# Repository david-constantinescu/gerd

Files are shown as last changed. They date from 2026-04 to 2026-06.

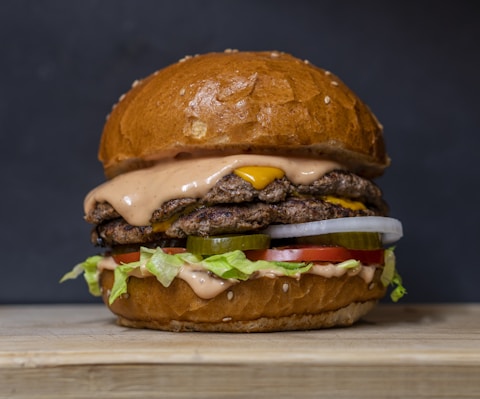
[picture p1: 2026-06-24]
simulator/scripts/food_fixtures/burger.jpg

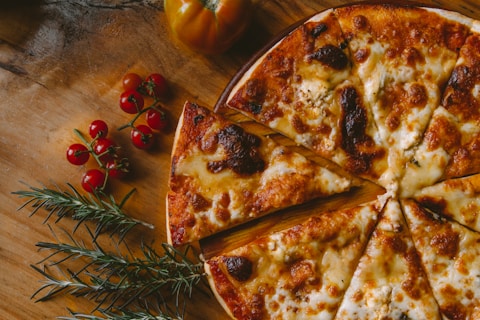
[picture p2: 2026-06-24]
simulator/scripts/food_fixtures/pizza.jpg

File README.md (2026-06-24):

# UpRight

An offline, waist-worn wearable for people with GERD / acid reflux. Runs on a
Raspberry Pi Zero 2 W.

> Reference docs live in `reference docs/`. Start with
> [`oled-mockups.md`](reference%20docs/oled-mockups.md) for on-device UI layout and
> **two-button** controls (GPIO 20 / 21 — no rotary encoder).

## What it does

- **Posture tracking** with an MPU6050 IMU; vibration + voice alerts when you
  slouch, with a 2 minute lying-down grace period and configurable cooldowns.
- **Food risk analysis** — point the OV9712 camera at your meal; a bundled,
  on-device TFLite model (Google's AIY Food V1, 2024 food classes) **names the
  dish**, then maps it to a GERD risk tier + how long to stay upright using a
  ~380-entry food dictionary plus a keyword fallback. Result + spoken advice on
  the OLED.
- **Sleep position** tracking with up to 3 vibration nudges per night when
  you roll onto your right side / back / front.
- **Posture** via MPU6050 IMU on the waist clip.
- **Medication reminders** with button-press acknowledgment.
- **Local Flask PWA** dashboard reachable at `http://<hostname>.local` (mDNS)
  on your own Wi-Fi. First-time setup needs no app: with no network configured the
  device raises a temporary **UpRight-Setup** Wi-Fi AP — scan the on-screen Wi-Fi
  QR to join it, and a **captive portal** opens the Wi-Fi picker on your phone by
  itself (no URL to type). Add/switch networks later from Settings → Network.
- **Self-maintaining clock** — the RTC-less Pi keeps correct time via chrony +
  fake-hwclock, with an HTTP-time fallback for networks that block NTP.

No cloud, no app store.

The full subsystem layout and milestone breakdown lives in
[`reference docs/BUILD.md`](reference%20docs/BUILD.md). Wiring pinout in
[`reference docs/WIRING.md`](reference%20docs/WIRING.md). Mac → GitHub → Pi dev
workflow in [`reference docs/DEV.md`](reference%20docs/DEV.md). **For a complete
project brief / agent handoff (current state + the open Wi-Fi-AP issue), read
[`reference docs/HANDOFF.md`](reference%20docs/HANDOFF.md).**

## Quick start (on a fresh Pi Zero 2 W)

```bash
curl -fsSL https://raw.githubusercontent.com/david-constantinescu/gerd/main/install.sh | bash
```

This clones the repo, installs every system + Python dependency (including the
`ai-edge-litert` runtime for the food model), enables I²C and I²S, enables mDNS
(avahi) + NetworkManager, configures the setup-AP captive portal and time sync,
and installs both systemd units (`upright.service` for the firmware loop,
`upright-web.service` for the Flask PWA). Pre-seed the first Wi-Fi network with
Raspberry Pi Imager, or use the on-device **UpRight-Setup** AP on first boot;
after that, manage networks from the dashboard's Settings → Network page.

> The bundled food model is a ~20 MB binary committed to the repo. The Pi runs
> **Debian 13 (trixie)** on Python 3.13, where the runtime must be
> `ai-edge-litert` (`tflite-runtime` has no 3.13 wheel) — `install.sh` handles
> this. To flash an SD card directly from macOS instead of booting the Pi, see
> the `e2fsprogs`/`e2tools` workflow in
> [`reference docs/HANDOFF.md`](reference%20docs/HANDOFF.md) §8.

## Quick start (development on macOS)

```bash
git clone https://github.com/david-constantinescu/gerd.git
cd gerd/firmware
python3 -m venv .venv && source .venv/bin/activate
pip install -e ".[dev]"
pytest -q
python -m upright.main --dry-run
```

The HAL imports its Pi-only libraries lazily (`RPi.GPIO`, `smbus2`,
`luma.oled`) so the package imports cleanly on macOS for unit tests, even though
the actual hardware drivers can't run there. The food model runs on macOS too if
you `pip install ai-edge-litert` (the same runtime used on the Pi). The
[simulator](simulator/README.md) runs the whole firmware against a virtual HAL.

## Repo layout

```
firmware/         Python package that runs on the Pi
  src/upright/   Source: HAL, FSM, services, web app
  models/         Bundled food classifier (.tflite + .labels.txt)
  scripts/        Per-sensor bring-up helpers
  systemd/        Service files (firmware loop + Flask PWA)
  tests/          pytest, runs on Mac (104 tests)
  data/foods.json Food risk dictionary (~380 entries)
simulator/        Virtual Pi bench: real firmware + sim HAL + HTTP API
scripts/          Pi install + ops helpers (incl. upright-set-time)
reference docs/   HANDOFF, BUILD, DEV, WIRING, PI_REMOTE_RUNBOOK, mockups, spec
cad/              Enclosure CAD (placeholder)
install.sh        One-shot Pi installer (idempotent)
```

## License

MIT.

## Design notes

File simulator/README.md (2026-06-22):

# UpRight — Raspberry Pi Simulator

A **virtual Raspberry Pi bench** that runs the *real* firmware from
[`../firmware`](../firmware) with a simulated hardware layer, surfaced through a
browser UI and an HTTP control API.

You click buttons, drag posture/battery sliders, and stream your webcam — and
the actual `upright` firmware (boot sequence, finite-state machine, menu system,
posture detection, alert/haptics, the *exact* `ui.render` frames it pushes to
the OLED/TFT) reacts as if it were on the device. The screen you see is the
genuine 160×128 ST7735R panel output, rendered by the firmware itself.

> **Why not QEMU?** A full-system emulator boots the ARM CPU and Linux, but it
> does **not** emulate the GPIO buttons, I²C IMU, SPI TFT, or USB camera — the
> peripherals that *are* this firmware. Under QEMU the code falls back to the
> same empty stubs it uses on a Mac. This simulator instead runs the real
> Python firmware natively (Python behaves identically to the Pi) and provides
> interactive, faithful simulation of the peripherals — which is *more* accurate
> for this project, not less.

## What is real vs. simulated

| Layer | In the simulator |
|---|---|
| Boot sequence, FSM, menus, services, posture/sleep/meds logic | **Real firmware code, unmodified** |
| `ui.render` → display frames (160×128 RGB) | **Real** — captured and streamed to the browser |
| Web-app inbox commands (meal, symptom, calibrate, …) | **Real** — same SQLite inbox path as the PWA |
| Buttons A/B, encoder | Simulated → real `BUTTON_PRESS` / `ENCODER_*` events |
| IMU (pitch/roll) | Simulated from sliders → real `POSTURE_SAMPLE` events (incl. EMA smoothing) |
| Battery, heart-rate | Simulated → real `POWER_SAMPLE` / `HRV_SAMPLE` events |
| Camera (USB UVC) | Your **webcam** (or an uploaded image) → real `camera.capture()` |
| Motor (haptics), audio | Captured and shown as indicators in the UI |

The firmware's HAL has a clean seam (lazy hardware imports + `--dry-run`), so the
simulator swaps only the lowest layer via monkeypatching — **the firmware source
is never touched.** See [`sim/hal_sim.py`](sim/hal_sim.py).

## Run it

```bash
cd simulator
# use the firmware venv (already has flask + pillow + numpy):
../firmware/.venv/bin/python run.py
# → open http://localhost:8000
```

Flags:

| Flag | Effect |
|---|---|
| `--port 9000` | listen on a different port (default 8000) |
| `--fresh` | reset the `.simdata` sandbox before starting |
| `--demo` | enable `demo_mode` (synthetic week data; disables live posture control) |
| `--open` | open the bench in your default browser |

Firmware data is sandboxed in `simulator/.simdata/` (seeded once from
`firmware/data/`), so running the simulator **never clobbers the real device DB.**

## HTTP / JSON control API (AI-controllable)

Any agent can drive the device with plain HTTP. The screen is readable as a PNG
(for vision models) and the full state as JSON.

| Method & path | Body | Purpose |
|---|---|---|
| `GET /api/state` | — | FSM state, menu, sensors, motor/audio, log tail |
| `GET /screen.png?scale=N` | — | current panel frame as PNG (native 160×128 × N) |
| `GET /stream.mjpeg` | — | live MJPEG screen stream |
| `POST /api/button` | `{"button":"a\|b","pattern":"single\|double\|triple"}` | press a button |
| `POST /api/encoder` | `{"action":"cw\|ccw\|click"}` | rotate/click encoder |
| `POST /api/posture` | `{"pitch":<deg>,"roll":<deg>}` | set IMU posture |
| `POST /api/battery` | `{"pct":0-100,"low":bool}` | set battery |
| `POST /api/hrv` | `{"bpm":<n>,"rmssd":<ms>}` | inject a heart-rate sample |
| `POST /api/camera/frame` | raw `image/*` bytes, or `{"image":"<dataURL\|base64>"}` | feed a camera frame |
| `POST /api/command` | `{"command":"<name>","payload":{…}}` | queue a web-app inbox command |

`/api/command` names mirror the real PWA: `meal`, `symptom`, `water`,
`calibrate`, `open_menu`, `sleep`, `haptic`, `idle`, `demo_enter`, `demo_exit`,
`med_ack`, `config_reload` (raw inbox kinds like `cmd_open_menu` also accepted).

### Example: an agent drives the device

```bash
B=http://localhost:8000
curl -s $B/api/command -d '{"command":"open_menu"}' -H 'Content-Type: application/json'
curl -s $B/api/button  -d '{"button":"a"}'          -H 'Content-Type: application/json'   # navigate
curl -s $B/api/button  -d '{"button":"b"}'          -H 'Content-Type: application/json'   # select
curl -s $B/api/posture -d '{"pitch":35,"roll":2}'   -H 'Content-Type: application/json'   # slouch
curl -s $B/screen.png?scale=4 -o screen.png                                                # read the screen
curl -s $B/api/state | python -m json.tool                                                 # read the state
```

## Layout

```
simulator/
├── run.py            # entrypoint: boots firmware + serves the bench
├── sim/
│   ├── runner.py     # path/data sandbox, imports firmware, runs main() in a thread
│   ├── hal_sim.py    # simulated HAL backends + monkeypatch installer (no firmware edits)
│   ├── server.py     # Flask: bench UI + control API + screen stream
│   └── state.py      # SimDevice: thread-safe bridge (inputs ⇄ outputs ⇄ frames)
└── web/              # the browser bench (index.html, bench.css, bench.js)
```

## Notes & limits

- The encoder is *not fitted* on the real hardware (shares GPIO with the motor),
  so the firmware mostly ignores encoder events — the controls are provided for
  completeness.
- Food-photo classification runs for real in the sim: the bundled AIY Food model
  ships in `firmware/models/`, and `pip install ai-edge-litert` (in
  `requirements.txt`) provides the runtime on macOS. Enable the webcam or upload a
  food image, capture, and you get a real dish name + GERD risk. Without the
  runtime it degrades to "Not recognized".
- Posture alerts/haptics fire under the firmware's real timing/threshold rules
  (sustained slouch, post-meal strictness, etc.) — set a slouch and wait.

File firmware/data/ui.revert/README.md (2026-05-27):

# UI revert snapshot

Saved **before** battery icon + two-button navigation update (A tap=up, A hold=back, B tap=down, B hold=select).

Restore on Mac or Pi:

```bash
bash firmware/scripts/ui_revert.sh
sudo systemctl restart upright   # on Pi
```

Files: `ui.py`, `ui_theme.py`, `button.py`, `manager.py`, `menu.py`

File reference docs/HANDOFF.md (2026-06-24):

# UpRight — Engineering Handoff & Agent Brief

> **Purpose of this file.** A single, self-contained brief so another engineer
> or AI agent can pick up this project cold. It carries the full context: what
> the device is, how the code is laid out, what has been built recently, the
> exact dev/build/flash/SSH environment, and the **open problem** (Wi-Fi setup
> AP on real hardware). Read this top to bottom before touching anything.
>
> Last updated: 2026-06-21. Repo HEAD at handoff: `5feb4fa` on `main`.

---

## 1. What the product is

**UpRight** is an **offline, waist-worn wearable for people with GERD / acid
reflux**, built on a **Raspberry Pi Zero 2 W**. Everything runs on-device — no
cloud, no app store, no companion app required.

Features:
- **Posture tracking** (MPU6050 IMU) → vibration + spoken alerts on slouch, with
  a lying-down grace period and cooldowns.
- **Food risk analysis** — point the OV9712 USB camera at a meal, an on-device
  TFLite model names the dish, and it's mapped to a GERD risk tier + how long to
  stay upright. (See §4 — this was just made to actually work.)
- **Sleep position** tracking with vibration nudges when you roll onto your
  right/back/front.
- **Posture** via MPU6050 IMU (no heart-rate sensor on this hardware revision).
- **Medication reminders** with button-press acknowledgment.
- **Local Flask PWA** dashboard at `http://<hostname>.local`, plus first-time
  Wi-Fi onboarding via an on-screen QR (see §5).

Two physical buttons (GPIO 20 / 21), a 160×128 ST7735R SPI TFT, a vibration
motor, and an I²S speaker. No rotary encoder despite some legacy naming.

---

## 2. People, accounts, machines

| Thing | Value |
|---|---|
| GitHub repo | `https://github.com/david-constantinescu/gerd` (branch `main`) |
| `gh` CLI auth | authenticated as `david-constantinescu` |
| Owner email | david.constantinescu1982@gmail.com |
| Local checkout (macOS) | `~/Downloads/upright/gerd` |
| Pi hostname | `softhoarders-pi` (mDNS `softhoarders-pi.local`) |
| Pi user | `softhoarders` |
| Pi project path | `~/upright` (i.e. `/home/softhoarders/upright`) |
| Web dashboard login | `softhoarders` / `0031` |
| Pi OS | **Debian 13 (trixie)**, NetworkManager-managed |
| Pi Python | **3.13**, venv at `~/upright/.venv` created `--system-site-packages` |

> Note the Pi runs plain **Debian 13 trixie**, not "Raspberry Pi OS Bookworm".
> This matters for package/runtime availability (see §4 runtime note).

---

## 3. Repo layout & architecture

```
firmware/                  Python package that runs on the Pi
  src/upright/
    main.py                entrypoint; starts HAL threads + ModeManager loop
    config.py              Tunables dataclass + all file paths (DATA_DIR, MODELS_DIR…)
    events.py              EventBus (queue.Queue) + EventType enum
    hal/                   hardware abstraction (lazy Pi-only imports)
      display.py camera.py button.py imu.py motor.py audio.py power.py …
    modes/
      manager.py           ModeManager — the FSM + view-context builder + render loop
      menu.py              two-button menu navigation state
      ui.py / ui_theme.py  OLED renderers (PIL → 160×128)
      states.py            State enum
    services/
      foods.py             food dictionary + TFLite inference (see §4)
      logger.py            SQLite store (self-healing on corruption)
      wifi.py              NetworkManager (nmcli) wrapper + setup-AP funcs
      provisioning.py      raises/drops the setup AP; is_setup_mode()
      netinfo.py           hostname/IP/QR helpers (segno)
      timesync.py          keep the clock correct (chrony nudge + HTTP-Date)
      alerts.py meds.py sleep.py analytics.py demo_seed.py boot.py
    web/
      app.py               Flask PWA + JSON API + captive-portal hook
      templates/           dashboard.html, settings.html, setup.html, …
      static/              app.js, style.css, sw.js
  models/                  food_mobilenetv2_quant.tflite (+ .labels.txt)
  data/                    foods.json, config.json, display.default.json
  systemd/                 upright.service, upright-web.service (@USER@/@DIR@ templated)
  tests/                   pytest (runs on Mac), 104 tests
simulator/                 virtual Pi bench (runs real firmware w/ sim HAL) — see simulator/README.md
scripts/                   pi-install-*.sh, deploy-to-pi.sh, upright-set-time
reference docs/            this file + BUILD/DEV/WIRING/PI_REMOTE_RUNBOOK/…
install.sh                 one-shot Pi installer (idempotent)
```

**Key architecture facts (not obvious from a quick read):**
- The HAL imports Pi-only libs **lazily**, and `main.py` supports `--dry-run`, so
  the package imports and the test suite run on macOS with no hardware.
- Firmware ↔ web talk **only** through the SQLite `inbox` table (polling IPC);
  there is no direct call path between the two processes.
- Rendering is gated: `ModeManager` only repaints the OLED when a "view
  signature" changes, to avoid SPI thrash.
- Two systemd units: `upright.service` (firmware loop, `User=softhoarders`) and
  `upright-web.service` (gunicorn on :80, has `CAP_NET_BIND_SERVICE`). **Both run
  as the non-root user** — so anything needing root (setting the clock) goes
  through a sudoers-allowed helper, not directly.

---

## 4. Food classification — DONE (bundled a real model)

**Problem it fixes:** the food flow never recognized anything because no model
shipped (only a labels file), so `classify()` always returned `None` and the
result screen dead-ended on "unknown / 0%".

**What was done (commit `13bee30`):**
- Bundled **Google's AIY Food V1** quantized TFLite model (2024 food classes,
  ~20 MB, input 192×192 uint8, output uint8 softmax). It lives at
  `firmware/models/food_mobilenetv2_quant.tflite` and is **un-gitignored** (an
  exception in `.gitignore`) so it ships in git and to the SD.
- `foods.py`:
  - `_load_interpreter_cls()` tries `ai_edge_litert` → `tflite_runtime` →
    `tensorflow.lite` (whichever is present).
  - `resolve_label()` keeps the **detected dish name** and maps it to a GERD risk
    tier via `foods.json` (exact/alias, then longest whole-word match), then a
    **keyword fallback** (`_HIGH_RISK_KW`/`_LOW_RISK_KW`: fried/citrus/tomato/
    coffee/chocolate… → HIGH; veg/grains/lean protein → LOW) so any recognized
    food yields useful advice. The model's `__background__` class → `None`.
  - `food_min_confidence` lowered `0.60 → 0.20` (a 2024-class top-1 for real food
    is ~0.3–0.85; non-food sits < 0.15). Set in `config.py` and `data/config.json`.
- `ui.py` ASCII-folds OLED text — the built-in PIL bitmap font renders an em
  dash and accented names (e.g. "Rösti") as a blank "tofu" box.
- Verified end-to-end in the simulator: real photos classify correctly
  (croquettes→"Croquette", pizza→"Neapolitan pizza"/HIGH/score 95), non-food →
  "Not recognized".

**Runtime gotcha (important):** `tflite-runtime` has **no cp313 wheel**, and the
Pi venv is Python 3.13 → the only working runtime there is **`ai-edge-litert`**.
Its `Interpreter` only needs `numpy` at runtime (the protobuf/tqdm deps are for
conversion tools), so it can be vendored as a single wheel. It's listed in the
`[pi]` extra and `simulator/requirements.txt`. On macOS (the sim) `ai-edge-litert`
installs cleanly and runs the model.

---

## 5. Networking & first-time Wi-Fi

> **ROOT CAUSE FOUND & FIXED (2026-06-24, commit `5907a23`).** The device
> "wouldn't connect to anything and the setup AP wouldn't broadcast" because
> Raspberry Pi Imager configured Wi-Fi the **old ifupdown way** in
> `/etc/network/interfaces` *and* NetworkManager was left `[ifupdown]
> managed=false` — so **NM never managed `wlan0`**, and the entire nmcli-based
> firmware Wi-Fi stack silently couldn't touch the radio. Fix: `install.sh` (and
> a direct SD edit) strip the `wlan0` stanza from `/etc/network/interfaces`,
> migrate the ifupdown Wi-Fi into an NM keyfile, and drop
> `/etc/NetworkManager/conf.d/10-upright-manage-wifi.conf` (`managed=true`). Also
> removed a `wifi.py` autoconnect-suppression trap (it persisted
> `autoconnect=no` on saved networks → stranded the device offline forever), and
> added a **boot diagnostic** (`scripts/upright-netdiag.sh` +
> `upright-netdiag.service`) that writes `nmcli`/`iw`/`rfkill`/`dmesg` state to
> `<boot>/upright-netdiag.txt` each boot — readable straight off the SD's FAT
> partition, no SSH. **Still needs confirming on hardware:** boot the patched SD,
> then read `bootfs/upright-netdiag.txt` to see the live radio state.

Background on the design and the (now-fixed) symptoms follows.

### Design
- The old always-on Wi-Fi hotspot was removed in favor of **mDNS** (avahi,
  `softhoarders-pi.local`) + **NetworkManager** Wi-Fi management.
- **First-time provisioning:** when the device has no Wi-Fi, `provisioning.py`
  raises a temporary AP **`UpRight-Setup` / `uprightsetup`** at gateway
  `10.42.0.1` (NM `shared` mode). The OLED Network screen shows a standard
  `WIFI:` join QR. Once the device associates as a client, the AP drops.
- **Captive portal (commit `b0d2316`):** `install.sh` writes
  `/etc/NetworkManager/dnsmasq-shared.d/upright-captive.conf` with
  `address=/#/10.42.0.1`, so while the AP is up every DNS query resolves to the
  gateway. `web/app.py` has a `before_request` hook that, during
  `provisioning.is_setup_mode()`, redirects OS captive-portal probes
  (Android/iOS/Windows/Firefox) and foreign hosts to a clean, **login-free**
  `templates/setup.html` Wi-Fi picker — so the phone auto-opens the setup page
  after joining. On connect it shows the dashboard URL + QR.
- The QR codes were verified decodable with a real reader (OpenCV
  `QRCodeDetector`), including at the 99×99 size rendered on the 128 px panel.

### AP-hardening already applied (commit `5feb4fa`, NOT yet verified on hardware)
`wifi.start_ap()` was hardened because the AP would not broadcast on a real boot:
- It **frees the single radio first** (`nmcli device disconnect wlan0`) — a saved
  network NM keeps auto-retrying otherwise hogs `wlan0` and blocks AP activation.
- It **recreates the profile each time** with explicit WPA2/RSN ciphers
  (`proto rsn`, `pairwise/group ccmp`) and a **fixed 2.4 GHz channel 6** — the
  bare `key-mgmt wpa-psk` form can leave `wpa_supplicant` unable to beacon on some
  `brcmfmac` builds.
- Boot grace cut `30s → 12s` so the AP appears quickly when the saved network is
  unreachable.
- The OLED **online** Network screen now also prints the **LAN IP** under the QR,
  so the device is reachable even when `<host>.local` won't resolve.

### ⚠️ OPEN PROBLEM (where the next agent starts)
On the real Pi the user reports: **"I can scan the QR but it won't connect, and
the `UpRight-Setup` network isn't broadcasting."** Diagnosis so far (all from
inspecting the SD card, since there are **no persistent logs** — the journal is
volatile and gone on reboot):
- Regulatory is fine: `cfg80211.ieee80211_regdom=RO` is set in
  `bootfs/cmdline.txt` (Pi Imager seeded it) and `/lib/firmware/regulatory.db`
  exists. So "no country" is **not** the cause.
- `rfkill` wlan state on disk = `0` (not blocked).
- NetworkManager + `nmcli` installed and enabled; `wpa_supplicant.service` enabled.
- There is a **pre-seeded client profile** `DIGI-Y7wu` (the owner's home ISP),
  `autoconnect` default true. So on boot NM tries to join it.
- The hardened `start_ap()` (free-radio + RSN + ch6) is the current best guess but
  **has not been confirmed on hardware yet.**

To make the Pi reachable for live debugging, a **`SoftHoarders Wi-Fi`** client
profile (psk `SoftHoarders`, `autoconnect-priority=10`) was written directly to
the SD at `/etc/NetworkManager/system-connections/` (mode 0600, root-owned). The
owner's Mac SSH key is **already in** `~softhoarders/.ssh/authorized_keys`, and
`ssh.service` is enabled — so SSH should work **once the Pi and the controlling
machine are on the same network.**

**Current blocker:** the controlling Mac is on **wired ethernet** (`192.168.0.x`);
the Pi joined **`SoftHoarders Wi-Fi`** (a different subnet), so they can't see
each other. A full `192.168.0.0/24` port-22 scan + key-auth probe did **not** find
the Pi (only an unrelated Ubuntu box `softhoardersmuzeu` shares the key).

**Open questions to resolve next:**
1. Is `SoftHoarders Wi-Fi` **2.4 GHz**? The Pi Zero 2 W is 2.4 GHz-only; a
   5 GHz-only hotspot would explain "can't join" entirely.
2. Put the controlling machine on the **same network** as the Pi (or read the
   device's **Settings → Network** screen for the IP it shows) to get SSH access.
3. With SSH access, debug the AP **live** — the right tools are:
   `nmcli -f WIFI-PROPERTIES device show wlan0` (does the driver advertise AP?),
   `sudo nmcli connection up upright-setup` (read the actual failure),
   `iw dev`, `iw reg get`, `dmesg | grep -i brcmfmac`, `journalctl -u NetworkManager -b`.
4. Consider enabling **persistent journald** on the Pi
   (`mkdir -p /var/log/journal && systemctl restart systemd-journald`) so the
   next failure leaves logs.

---

## 6. Clock / time sync — DONE (commits `b0d2316`, `cf9c8ba`)

The Pi Zero 2 W has **no RTC**, so its clock lagged.
- `install.sh` installs/enables **chrony** (`makestep 1 -1`) + **fake-hwclock**
  and sets NTP on — clock is disciplined continuously and survives reboots.
- `services/timesync.py` (started from `main.py`): forces a chrony step on
  boot/network-up and, on networks that block NTP (UDP 123), sets the clock from
  an **HTTPS `Date` header** via the narrow sudo helper
  `scripts/upright-set-time` (allowed in `/etc/sudoers.d/upright-timesync`). It
  runs even when chrony isn't installed, as long as the helper is present — so a
  hand-flashed board still self-corrects.

---

## 7. Dev / build / test (macOS)

```bash
cd ~/Downloads/upright/gerd/firmware
python3 -m venv .venv && source .venv/bin/activate   # already exists in the checkout
pip install -e ".[dev]"          # + `ai-edge-litert` to run the food model locally
.venv/bin/python -m pytest -q    # 104 tests, must stay green
.venv/bin/ruff check src tests   # CI runs this too — must be clean
python -m upright.main --dry-run # run the firmware off-Pi
```

**Simulator** (runs the *real* firmware with a simulated HAL + browser bench +
HTTP control API — the best way to verify UI/flows without hardware):
```bash
cd ~/Downloads/upright/gerd/simulator
../firmware/.venv/bin/python run.py --port 8000   # open http://127.0.0.1:8000
```
Drive it over HTTP: `POST /api/button {button,pattern}`, `/api/posture`,
`/api/camera/frame` (raw JPEG), `/api/command {command}`; read `/api/state`,
`/screen.png`. See `simulator/README.md`.

CI = `ruff check firmware/src firmware/tests` + `pytest`. Keep both green.

---

## 8. Deploying to the Pi

There are **two** deploy paths. Prefer the first.

### A. On the Pi (recommended — applies system config too)
```bash
cd ~/upright && git pull && sudo bash install.sh && sudo reboot
```
This pulls code + the bundled model, installs the `ai-edge-litert` runtime, and
applies the system-level pieces (captive-portal dnsmasq config, chrony,
sudoers + time helper). The food model and the timesync HTTP fallback work from
code alone, but **the captive portal and chrony only fully activate after
`install.sh` runs on the Pi.**

### B. Flash the SD card from macOS (offline, no Pi boot needed)
The Pi rootfs is **ext4**, which macOS can't mount — use `e2fsprogs`/`e2tools`.

```bash
# tools (installed via Homebrew):
export PATH="/usr/local/opt/e2fsprogs/sbin:/usr/local/opt/e2fsprogs/bin:$PATH"
#   e2fsck, debugfs live there; e2cp / e2mkdir / e2ls live in /usr/local/bin

SD=/dev/disk8s2          # ext4 rootfs (the Linux partition; check `diskutil list`)
                         # bootfs (FAT) auto-mounts at /Volumes/bootfs — edit directly

# sudo on this Mac needs Touch ID, which only surfaces when the Bash sandbox is
# OFF. In Claude Code: run Bash with dangerouslyDisableSandbox: true.

sudo e2fsck -fy "$SD"                                   # ALWAYS before & after writing
# read:  sudo debugfs -R "cat /path" "$SD"   (batch many: debugfs -f cmds.txt "$SD")
# write: sudo e2cp -O 1000 -G 1000 -P 0644 local "$SD:/home/softhoarders/upright/…"
#        (use -O 0 -G 0 for root-owned files under /etc, /usr/local/sbin)
# mkdir: sudo e2mkdir "$SD:/path/to/dir"
sudo e2fsck -fn "$SD"; sync; diskutil eject disk8       # finish clean, then eject
```

Things already vendored onto the SD this way (since the Pi was offline / to avoid
re-running install): the food **model**, the **`ai_edge_litert`** runtime
(cp313/aarch64 wheel extracted into `…/.venv/lib/python3.13/site-packages/`),
**`segno`**, the captive-portal/chrony/sudoers config, the `upright-set-time`
helper, and the `SoftHoarders Wi-Fi` NM profile. Verify writes by md5-comparing
files read back with `e2cp` against the repo.

> Editable install: the Pi venv uses a lax `.pth` pointing at
> `~/upright/firmware/src`, so **new Python modules are importable without a
> reinstall** — copying a `.py` file in is enough.

---

## 9. Connecting to the Pi (SSH + finding it on the LAN)

```bash
ssh softhoarders@softhoarders-pi.local         # if mDNS resolves
# the Mac's key is already in the Pi's authorized_keys
```
If mDNS doesn't resolve (common on some networks), find it by IP. **Both machines
must be on the same network/subnet.**
```bash
# scan the local /24 for SSH, then key-auth probe to find the Pi by hostname:
for i in $(seq 1 254); do (nc -G1 -z -w1 192.168.0.$i 22 2>/dev/null && echo .$i) & done; wait
for ip in <candidates>; do
  ssh -o BatchMode=yes -o StrictHostKeyChecking=accept-new -o ConnectTimeout=4 \
      softhoarders@192.168.0.$ip 'hostname' 2>/dev/null
done   # the Pi answers "softhoarders-pi"
```
See `PI_REMOTE_RUNBOOK.md` for service/ops commands once connected.

---

## 10. Status summary & prioritized next steps

**Done & on `main`:** real food classifier + runtime, mDNS, captive-portal Wi-Fi
setup page, clock sync, AP hardening. 104 tests pass, ruff clean. Model + runtime
+ config flashed to the SD; `SoftHoarders Wi-Fi` + SSH key in place.

**Not yet verified on hardware:** the `UpRight-Setup` AP actually broadcasting,
and the food model running on-device (both need a booted, reachable Pi).

**Do next, in order:**
1. **Get SSH on the Pi.** Put the controlling machine on the **same network** the
   Pi joined (`SoftHoarders Wi-Fi`), or use the IP shown on the device's
   Settings → Network screen. Confirm 2.4 GHz (the Pi is 2.4 GHz-only).
2. **Verify the food flow on-device:** trigger a food photo, confirm
   `ai_edge_litert` loads and a dish is recognized. (`journalctl -u upright -f`.)
3. **Fix the setup AP live** using the §5 commands; confirm `UpRight-Setup`
   beacons and a phone can join + auto-open the portal. Update `wifi.start_ap()`
   based on the real `nmcli`/`dmesg` error and add a regression test.
4. **Enable persistent journald** so future failures are debuggable.
5. Push every change to `main`; keep `pytest` + `ruff` green.

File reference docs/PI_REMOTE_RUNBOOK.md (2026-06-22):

# Pi Remote Runbook (SSH + Ops)

This is the practical reference for connecting to the project Pi and managing
the running UpRight app remotely.

## Target machine

- Hostname: `softhoarders-pi.local`
- User: `softhoarders`
- Project path on Pi: `~/upright`
- Firmware path: `~/upright/firmware`

## 1) SSH access

### First-time key setup (Mac)

```bash
# generate key if needed
test -f ~/.ssh/id_ed25519 || ssh-keygen -t ed25519 -C "upright-dev"

# copy key to Pi
ssh-copy-id softhoarders@softhoarders-pi.local
```

### Connect

```bash
ssh softhoarders@softhoarders-pi.local
```

### Quick connectivity check

```bash
ssh -o ConnectTimeout=10 softhoarders@softhoarders-pi.local 'echo up && uptime'
```

## 2) Service lifecycle (systemd)

The app is managed by:

- `upright` (firmware loop + display + hardware)
- `upright-web` (web UI on port 80)

### Verify auto-start after reboot

```bash
ssh softhoarders@softhoarders-pi.local \
  'systemctl is-enabled upright upright-web; systemctl is-active upright upright-web'
```

Expected: both `enabled` and both `active`.

### Restart app stack

```bash
ssh softhoarders@softhoarders-pi.local \
  'sudo systemctl restart upright upright-web'
```

### Logs

```bash
ssh softhoarders@softhoarders-pi.local \
  'journalctl -u upright -n 80 --no-pager'
```

Live tail:

```bash
ssh softhoarders@softhoarders-pi.local \
  'journalctl -u upright -f'
```

## 3) Deploy updated code from Mac

From repo root on Mac:

```bash
./scripts/deploy-to-pi.sh
```

Then on Pi:

```bash
ssh softhoarders@softhoarders-pi.local \
  'sudo systemctl restart upright upright-web'
```

## 4) Web app checks

### Local on Pi

```bash
ssh softhoarders@softhoarders-pi.local \
  'curl -s -o /dev/null -w "http:%{http_code}\n" http://127.0.0.1/'
```

Expected: `http:200`

### LAN access

Open from another device:

- `http://softhoarders-pi.local/`

## 5) Hardware checks over SSH

### Full suite (recommended)

```bash
ssh softhoarders@softhoarders-pi.local \
  'cd ~/upright/firmware && PYTHONPATH=src python3 scripts/pi_test_all.py'
```

### Bring-up-only check

```bash
ssh softhoarders@softhoarders-pi.local \
  'sudo systemctl stop upright; cd ~/upright/firmware && PYTHONPATH=src python3 scripts/pi_bringup_all.py; sudo systemctl start upright'
```

### SPI/display focused checks

```bash
# SPI node + transfer smoke
ssh softhoarders@softhoarders-pi.local \
  'cd ~/upright/firmware && PYTHONPATH=src python3 scripts/spi_scan.py'

# Direct TFT frame render test
ssh softhoarders@softhoarders-pi.local \
  'sudo systemctl stop upright; cd ~/upright/firmware && PYTHONPATH=src ~/upright/.venv/bin/python scripts/display_soak_test.py; sudo systemctl start upright'
```

## 6) Current hardware profile (important)

This build currently assumes:

- Display: Adafruit `ST7735R` over SPI (`/dev/spidev0.0`)
- Display config file: `~/upright/firmware/data/display.json`
- Buttons: physical header pins `38` and `40` (BCM `20` and `21`)
- Zero LiPo low-battery alert: BCM `4`
- HR sensor: not fitted (HRV path disabled)

## 7) Common failure patterns

### A) Web up, display blank/garbled

Run:

```bash
ssh softhoarders@softhoarders-pi.local \
  'cat ~/upright/firmware/data/display.json; ls -la /dev/spidev*'
```

Then force known-good display config:

```bash
ssh softhoarders@softhoarders-pi.local \
  'cp ~/upright/firmware/data/display.default.json ~/upright/firmware/data/display.json && sudo systemctl restart upright'
```

### B) App hangs in SPI transfer

Check process state:

```bash
ssh softhoarders@softhoarders-pi.local \
  'ps -o pid,stat,wchan:20,etime,cmd -p $(pgrep -f "python -m upright.main")'
```

If needed, hard restart:

```bash
ssh softhoarders@softhoarders-pi.local \
  'sudo systemctl stop upright; sudo pkill -9 -f "upright.main"; sudo systemctl start upright'
```

### C) SSH works but service not running

```bash
ssh softhoarders@softhoarders-pi.local \
  'sudo systemctl restart upright upright-web; systemctl is-active upright upright-web'
```

## 8) One-command snapshot for support

Use this to capture current status quickly:

```bash
ssh softhoarders@softhoarders-pi.local '
echo "== svc ==";
systemctl is-enabled upright upright-web;
systemctl is-active upright upright-web;
echo "== web ==";
curl -s -o /dev/null -w "http:%{http_code}\n" http://127.0.0.1/;
echo "== proc ==";
pgrep -af "python -m upright.main";
echo "== display ==";
cat ~/upright/firmware/data/display.json 2>/dev/null || echo no-display-config;
echo "== spi ==";
ls -la /dev/spidev* 2>/dev/null || echo no-spi
'
```

## 9) Finding the Pi when mDNS fails

`softhoarders-pi.local` doesn't always resolve. The Mac and Pi **must be on the
same network** (the Pi Zero 2 W is **2.4 GHz-only** — it can't join a 5 GHz-only
hotspot). To find it by IP:

```bash
# scan the local /24 for SSH hosts...
for i in $(seq 1 254); do (nc -G1 -z -w1 192.168.0.$i 22 2>/dev/null && echo .$i) & done; wait
# ...then key-auth probe each; the Pi answers its hostname
for ip in <candidates>; do
  ssh -o BatchMode=yes -o StrictHostKeyChecking=accept-new -o ConnectTimeout=4 \
      softhoarders@192.168.0.$ip 'hostname' 2>/dev/null
done   # the Pi answers "softhoarders-pi"
```
The device's **Settings → Network** OLED screen also prints the LAN IP under the
QR when it's online.

## 10) Wi-Fi management & first-time provisioning

- Networks are managed by **NetworkManager** (`nmcli`). Saved profiles live at
  `/etc/NetworkManager/system-connections/*.nmconnection` (mode `0600`, root).
- With **no** usable network, `provisioning.py` raises the **UpRight-Setup** AP
  (`uprightsetup`, gateway `10.42.0.1`). A captive portal auto-opens the setup
  page; or visit `http://10.42.0.1`.
- Add a network from the CLI: `sudo nmcli device wifi connect "<SSID>" password "<pw>"`.
- Debug the setup AP **live** (see also `HANDOFF.md` §5):
  ```bash
  nmcli -f WIFI-PROPERTIES device show wlan0   # does the driver advertise AP mode?
  sudo nmcli connection up upright-setup        # read the real activation error
  iw reg get; iw dev; dmesg | grep -i brcmfmac
  journalctl -u NetworkManager -b --no-pager | tail -50
  ```

## 11) Updating code on the Pi

```bash
# preferred — pulls model + applies system config (captive portal, chrony, sudoers)
ssh softhoarders@softhoarders-pi.local 'cd ~/upright && git pull && sudo bash install.sh'
ssh softhoarders@softhoarders-pi.local 'sudo systemctl restart upright upright-web'
```
The venv uses a lax editable `.pth`, so a plain `git pull` is enough to pick up
new/changed Python modules — only run `install.sh` when system packages or
`/etc` config changed. To flash an SD card directly from macOS (no Pi boot), see
`HANDOFF.md` §8 (`e2fsprogs`/`e2tools`).

## 12) Time sync

The Pi has **no RTC**. Time is kept by **chrony** + **fake-hwclock**, with a
firmware HTTP-`Date` fallback (`services/timesync.py` → `upright-set-time`).
Check: `timedatectl; chronyc tracking` (if chrony installed).

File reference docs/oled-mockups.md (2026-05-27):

# UpRight OLED UI mockups (128×64 logical)

Source: `oled menus.pdf`. The on-device TFT renders this layout scaled to **160×128** landscape.

## Controls (two buttons only)

| Button | GPIO | Default |
|---|---|---|
| **Top** | 20 | **Tap:** next option (wraps to top) · **Double-tap:** back / dismiss |
| **Bottom** | 21 | **Tap:** confirm highlighted · **Double-tap:** log symptom |

Control legend is shown on the **main menu** only; other screens have no button hints.

No rotary encoder is connected.

## Watch face (home)

```
┌────────────────────────────┐
│ 14:32    ●GOOD    ♥ 68bpm │
│ ─────────────────────────  │
│ Posture: ████████░░        │
│ Pitch: -3.2°          82%  │
│ Last meal: 1h 24m ago      │
│ Upright ✓                  │
└────────────────────────────┘
```

## Main menu (top tap from watch, or navigate from another screen)

```
┌────────────────────────────┐
│ ≡ MAIN MENU                │
│ ─────────────────────────  │
│ ▶ Log Meal                 │
│   Log Symptom              │
│   Medication               │
│   Settings                 │
│   Sleep Mode               │
│   About                    │
└────────────────────────────┘
```

**In menu:** top tap = next · top double = back · bottom tap = select · bottom double = log symptom.

## Quick reference

| Screen | Top tap | Top double | Bottom tap | Bottom double |
|---|---|---|---|---|
| Watch | Open main menu | — | — | Log symptom |
| Main menu | Next | Close / back | Select | Log symptom |
| Lists / yes-no | Next | Back | Select | — |
| Food photo | Next | Back | Select (capture) | Capture |
| Calibrate | — | Exit | — | Capture step |
| Med reminder | Next | Back | Acknowledge | Acknowledge |

Menus auto-close after **30 s** idle (returns to watch face).

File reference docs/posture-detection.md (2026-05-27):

# Posture detection — GERD rationale

Waist-worn **MPU6050 accelerometer** (not gyro-only). Pitch = forward/back trunk
tilt from calibrated upright; roll = side tilt for sleep position.

## What matters for reflux

| Risk | Why | Device signal |
|---|-----|---|
| **Slouch / trunk flexion** | Compresses abdomen, weakens gravity assist | `\|pitch\|` > ~12° (8° post-meal) |
| **Lying flat after eating** | Reflux episodes rise sharply vs upright | `\|pitch\|` ≥ ~55° for sustained period |
| **Right-side sleep** | Higher esophageal acid exposure vs left | Roll → sleep tracker nudges |
| **Stay upright post-meal** | Clinical guidance: 2–3 h after meals | POST_MEAL state + stricter thresholds |

Sources: postprandial reflux studies (upright vs recumbent), left vs right
lateral decubitus pH monitoring, lifestyle guidance on slouching and head-of-bed
elevation (~30° / 6–8 in for night, not pillow-only).

## Default thresholds (`config.json`)

| Tunable | Default | Meaning |
|---|---|---|
| `pitch_alert_deg` | 12° | Daytime slouch alert |
| `pitch_alert_strict_deg` | 8° | Post-meal slouch |
| `lying_flat_deg` | 55° | Torso near horizontal |
| `lying_grace_seconds` | 120 s | Brief lie-down OK after meal |
| `lying_sustained_seconds` | 20 s | Alert after grace if still flat |
| `pitch_sustained_seconds` | 45 s | Slouch must persist before alert |
| `posture_deadzone_deg` | 5° | Ignore small sensor wobble |

## Calibration

Stand naturally upright → Calibrate → capture baseline pitch. Mounting on
left/right hip is handled for **sleep roll** via `wear_side`; pitch baseline
covers clip orientation for slouch.

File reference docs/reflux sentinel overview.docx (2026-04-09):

REFLUX SENTINEL

A Wearable Companion for People Living with Acid Reflux

Non-Technical Overview · 2026

# What Is Reflux Sentinel?

A small, discreet device that clips to your belt and quietly helps you manage acid reflux — all day, every day.

Acid reflux (GERD) is not just occasional heartburn. For millions of people, it is a constant, exhausting condition that shapes every meal, every sleep, and every moment spent lying down. Managing it well means tracking dozens of small daily habits — what you eat, how you sit, when you eat, how you sleep — all at once. That is impossible to do reliably in your head.

Reflux Sentinel is a wearable device about the size of a thick pager that clips to your waist, under or over clothing, and does that tracking for you. It monitors your posture, detects when you eat, tracks how you sleep, and gently nudges you back on track whenever something risky is happening — a quiet vibration, a soft spoken reminder, or both. Everything happens on the device itself: no internet, no cloud, no app subscription, no data shared with anyone.

Think of it as a silent, always-on health coach clipped to your belt — one that knows your habits and nudges you toward better ones, without ever being annoying about it.

# The Problem It Solves

People with GERD are told to follow a long list of guidelines every day:

- Stay upright for at least two to three hours after every meal
- Don't lie on your right side or back when sleeping
- Avoid specific trigger foods — which are different for every person
- Take medication at exactly the right time
- Keep stress low, since stress worsens reflux

The problem is that life keeps moving. You finish lunch and go back to work and forget the clock. You fall asleep and naturally roll onto your back without knowing. You can't remember if that discomfort after dinner was the pasta or the salad dressing. You can't see patterns in your own behaviour without tracking them obsessively — and nobody can do that reliably for months on end.

Reflux Sentinel handles the tracking, the reminders, and the pattern-spotting for you, automatically, without you having to think about it.

# What It Looks Like

The device is a compact, rounded rectangular slab — roughly the size of a large matchbox, or a thick pager from the 1990s. It is designed to look intentional and unobtrusive, not like a DIY gadget. It has a matte finish with smooth, rounded edges for comfort against the body.

Size | Approximately 8cm × 4cm × 2cm — similar to a glucose monitor or a thick credit card wallet.
Weight | Under 60 grams. You will forget it is there within minutes.
Clip | A firm, flexible clip on the back grips your belt, waistband, or waistband of trousers. It holds securely without pinching clothing.
Screen | A small, crisp display on the back face (visible through a window in the clip) shows your posture status, menus, and notifications.
Controls | One button on the top left for quick logging. One rotating dial (like a watch crown) on the top right for navigating menus.
Camera | A small lens on the front face for optional food photo analysis.
Speaker | Subtle grilles on the front face. Voice is soft and calm — not jarring.
Power | Plugs into your existing portable phone charger (power bank) in your pocket via a short cable. No internal battery to charge or replace.

It is worn at the waist, like a pager or a small radio. From a metre away, it looks like a medical accessory. From up close, it looks designed and intentional.

# How It Communicates With You

Reflux Sentinel uses three types of feedback, depending on the situation and time of day:

Gentle vibration | A quiet buzz against your body — discreet enough that nobody around you notices. Used for most daytime nudges and all night-time alerts.
Spoken voice | A calm, clear voice that speaks short reminders out loud through the built-in speaker. For example: "You have been sitting for two hours since your last meal — great work" or "Consider sitting upright for a little longer."
Screen display | Text and symbols on the small screen for menus, status, food analysis results, and settings.

The alerts are designed to be helpful, not nagging. There are built-in "cooling off" periods so the device does not repeat the same reminder every five minutes. At night, it only vibrates — it never speaks out loud while you are sleeping.

# Features in Detail

## 1 — Posture Monitoring

The device continuously senses the angle of your body using a motion sensor — the same type used in modern smartphones. It knows the difference between sitting upright, slouching forward, leaning back, or lying flat.

During the first few minutes of wearing it, you stand naturally and press a button to set your personal "upright" baseline. After that, the device measures your posture relative to that baseline — so it works correctly regardless of how tall you are or how you carry yourself.

If you start leaning back in a risky way, especially in the hours after a meal, it will give you a gentle vibration. If you straighten up, it notices and stops. It is reactive, not relentless.

You can tell the device which side of your body it is clipped to (left or right hip), and it adjusts its readings accordingly.

## 2 — Meal Logging

Logging a meal is a single long press on the top button. That is it. No typing, no app to open, no phone to unlock.

After a meal is logged, the device starts a two-to-three hour countdown. During that window, it pays extra attention to your posture and will nudge you if you lean back or lie down too early. Once the window passes, it relaxes back to normal monitoring.

You can also log how you are feeling — mild discomfort, moderate, or strong — using short button presses. Over time, these logs build a picture of your symptom patterns linked to times, meals, and postures.

## 3 — Food Photo Analysis

Press a button on the dial, point the front of the device at your plate, and press again. The device takes a photo and, within a few seconds, analyses it using built-in artificial intelligence — no internet connection required.

It identifies the type of food and cross-references it against a database of foods known to be risky or safe for reflux patients. The result appears on the small screen — something like "High risk: tomato-based dish" or "Low risk: plain grains" — and the device may also say it out loud.

You confirm the log with a click of the dial, and the meal is saved alongside its risk rating. This builds up, over weeks, into a personalised picture of which foods seem to correlate with your worst days.

The food database covers over 100 common food types and can be edited on your phone to add or adjust entries specific to your own known triggers.

## 4 — Sleep Monitoring

The device automatically detects when you have fallen asleep. It does this by noticing that your body has been still and flat for several minutes during the night hours (configurable, but typically 11pm to 7am).

Once in sleep mode, it silently monitors which side you are lying on. Sleeping on the left side is generally considered the best position for people with reflux — it keeps the stomach positioned below the oesophagus. Sleeping on the right side, back, or front can worsen reflux symptoms during the night.

If it detects you have rolled into a risky position, it gives a quiet vibration — gentle enough to prompt you to shift without waking you fully. It starts soft and escalates slightly if you do not move, but it gives up after a few attempts so your sleep is not ruined. It only does this a maximum of three times per night.

In the morning, a summary of your sleep positions, any disturbances, and overnight patterns is available when you connect your phone.

## 5 — Medication Reminders

Many people with GERD take medication on a schedule — proton pump inhibitors, antacids, or other prescriptions that work best when taken at specific times. Missing a dose, or taking one at the wrong time relative to meals, can reduce their effectiveness significantly.

Reflux Sentinel can be configured (from your phone) with one or more medication reminders at set times each day. When the time arrives, it vibrates and speaks a calm reminder. You acknowledge it with a single press of the top button. If you do not acknowledge within a few minutes, it reminds you once more.

All reminder times and acknowledgments are logged, so you have a record of your adherence over time.

## 6 — Hydration Reminders

Staying well hydrated helps manage reflux, but drinking too much at once — especially during or just after meals — can make it worse. The device can remind you to drink small amounts of water at regular intervals throughout the day, outside of meal windows.

## 7 — Stress & Heart Rate Monitoring

The clip mechanism presses a small optical sensor gently against your skin. This sensor reads the tiny changes in blood flow caused by your heartbeat — the same principle used by fitness trackers and medical pulse oximeters, but used here to measure heart rate variability (HRV).

HRV is a well-established indicator of physiological stress. A lower HRV over time often means your body is under more stress. Since stress is a known trigger for reflux, tracking HRV alongside your symptom logs gives a more complete picture of what is happening on difficult days.

The device does not alert you about stress directly — it simply logs the data and makes it visible in your history, so you and your doctor can see whether high-stress periods correlate with worse symptoms.

## 8 — Pattern Recognition

All the data the device collects — posture events, meals, symptoms, sleep positions, stress levels, food photos, medication timing — is stored on the device itself in a structured log.

Over days and weeks, the device builds a history that reveals patterns invisible to the naked eye. When you connect your phone, you can see timelines, charts, and summaries: which days were worst, what you ate on those days, how your sleep was the night before, whether stress was elevated.

This kind of longitudinal data is exactly what doctors and gastroenterologists find most useful when adjusting treatment — but it is nearly impossible to collect reliably without automation.

## 9 — Morning Report

Each morning, when you first connect your phone to the device, a short overnight summary is automatically available. It covers how long you were likely asleep, whether any sleep position alerts fired, how many times medication reminders were acknowledged, and an overall score for the previous day.

This report can be exported as a PDF directly from your phone — ready to share with your doctor or gastroenterologist at your next appointment.

# Connecting Your Phone

The device does not connect to the internet, and it does not need to. Instead, it broadcasts its own small private WiFi network — like a personal hotspot — that only your phone connects to. This keeps all your health data completely private.

When you want to view your data, check settings, or download a report, you simply:

- Enable WiFi on your phone and select the device's network — a QR code appears on the device screen that your phone camera can scan automatically, so you never need to type a password.
- Your phone's browser opens automatically and shows a clean, easy-to-read dashboard.
- When you are done, just disconnect. The device continues working normally.

The phone connection is optional and entirely at your control. The device works perfectly without it — the phone is just for reviewing data, adjusting settings, and exporting reports.

The dashboard works on any phone — iPhone or Android — with no app to install. It opens automatically in your browser, like a website, the first time you connect.

## What You Can See on Your Phone

Dashboard | Live posture status, today's events timeline, a quick logging shortcut, and a connection banner.
Food Log | All logged meals with photos, identified food type, risk rating, and any symptom logs nearby in time.
Sleep Chart | A visual timeline of last night's sleep positions, nudge events, and overall position quality.
Reports | Export your data as a spreadsheet, raw data file, or formatted PDF report — ready for your doctor.
Settings | Adjust reminder times, sleep hours window, meal countdown duration, food risk table, and medication schedules.

# Privacy and Data

Health data is deeply personal. Reflux Sentinel was designed with one principle above all others: your data never leaves the device unless you choose to take it off.

- No internet connection — ever. The device cannot send data anywhere even if it wanted to.
- No cloud service, no account, no login, no subscription.
- No microphone. The device can speak to you, but it cannot listen.
- Data is stored locally on the device. When you connect your phone, data syncs to your phone only — and only if you allow it.
- Export is always manual and deliberate. Nothing is sent automatically to anyone.

In an era where almost every health device sends your data to a server somewhere, Reflux Sentinel is deliberately different. What happens in your body stays in your hands.

# Who Is It For?

GERD patients | Anyone diagnosed with gastroesophageal reflux disease who wants better day-to-day awareness and behaviour support beyond medication alone.
People with lifestyle reflux | Those who experience frequent reflux triggered by meals, stress, or posture but have not yet sought formal diagnosis.
Gastroenterologists | Clinicians who want objective, longitudinal data from patients between appointments — data that is currently impossible to collect reliably.
Carers and families | Family members supporting someone who struggles to self-monitor due to age, cognitive load, or other conditions.
Researchers | Teams studying GERD patterns, treatment adherence, or lifestyle interventions who need a structured data collection tool.

# A Typical Day With Reflux Sentinel

Here is what using the device actually feels like, from morning to night:

- You clip the device to your belt in the morning, plug it into your power bank in your pocket, and go about your day.
- At breakfast, you long-press the button to log your meal. The device notes the time and starts its post-meal countdown.
- You take a photo of your breakfast with the device. It identifies it as eggs and toast — low risk — and confirms with a soft chime.
- Forty minutes later, you lean back in your chair at work. A gentle buzz on your hip reminds you to sit up. You do. The buzzing stops.
- Your 9am medication alarm fires — a soft voice says your reminder, you press the button to confirm.
- At lunch, you repeat the logging. The device registers that it has been two hours and fifteen minutes since breakfast, well within the safe window.
- After a stressful afternoon meeting, you notice your symptoms feel worse. You log a mild symptom event with two quick presses.
- You get home and decide to lie on the sofa. The device gives you a two-minute grace window, then a gentle vibration. You sit up.
- At night, you fall asleep. The device goes silent — no voice alerts. It monitors your sleep position quietly and gives one soft buzz at 2am when you roll onto your back. You shift without fully waking.
- In the morning, you open your phone, scan the QR code, and see last night's summary and today's posture score.

None of the above required you to open an app, remember to check something, or manually track anything except one button press per meal. Everything else happened automatically.

# Where This Is Going

Reflux Sentinel is currently in prototype stage, with a planned pilot study with gastroenterology patients at a university hospital in Romania. The goals for the pilot are to validate the device in real clinical use, gather patient and clinician feedback, and build an evidence base for its effectiveness.

Now (Prototype) | A single handcrafted device, fully functional, worn by individuals or used in a small pilot study. All features described in this document are operational.
Near future (Small batch) | A refined version with a thinner profile, integrated rechargeable battery, and a dedicated phone app — aimed at equipping a small cohort of clinic patients.
Longer term (Product) | A CE-marked medical device meeting EU regulatory requirements, with hospital-grade data export, clinical trial evidence, and a sustainable path to widespread use.

# In Summary

Reflux Sentinel is a wearable device for people living with acid reflux that:

- Monitors your posture all day and nudges you when you are in a risky position
- Logs meals with a single button press and tracks the post-meal window
- Analyses food photos instantly on the device to flag high-risk foods
- Monitors your sleep position and gently corrects it without waking you
- Reminds you to take medication on schedule
- Tracks your stress levels and correlates them with your symptoms
- Stores all your data privately on the device — never on the internet
- Connects to your phone over a private local network for data review and export
- Works without any app, subscription, account, or internet connection

It is discreet, comfortable, and designed to disappear into your daily routine — while quietly making that routine better for your health.

Reflux Sentinel · Developed in Craiova, Romania · 2026

REFLUX SENTINEL — Patient & Stakeholder Overview

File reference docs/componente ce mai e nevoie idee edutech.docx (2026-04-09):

POSTURE AND SLEEP SENSING

MPU6050 GY-521 breakout board — detects forward lean and sleep roll position via accelerometer and gyroscope — 23–35 Lei

10kΩ resistor — I2C pull-up stability — less than 1 Lei

JST-SH 1.0mm 4-pin connector pair — clean removable I2C connection to Pi — 3–5 Lei

Subsystem total: 26–41 Lei

HEART RATE AND STRESS SENSING

MAX30102 breakout board — optical PPG sensor for HRV and stress detection, mounted on clip inner face — 25–40 Lei

JST-SH 1.0mm 4-pin connector pair — I2C connection to Pi — 3–5 Lei

Subsystem total: 28–45 Lei

AUDIO OUTPUT

MAX98357A I2S amplifier breakout — digital amplifier driving the speaker from Pi I2S — 30–57 Lei

Speaker 28–32mm 8Ω 1W — voice alerts and spoken food advice — 8–20 Lei

Acoustic mesh fabric small piece — covers speaker grille holes, keeps debris out — 2–5 Lei

Subsystem total: 40–82 Lei

SILENT ALERTS

Coin vibration motor 10mm — silent nudges for sleep position, public alerts, button feedback — 5–10 Lei

NPN transistor 2N2222 or equivalent — drives motor from GPIO safely — 1–3 Lei

1kΩ resistor — transistor base current limiting — less than 1 Lei

1N4001 flyback diode — protects Pi GPIO from motor voltage spike — 1–2 Lei

Subsystem total: 7–16 Lei

DISPLAY

SH1106 or SSD1306 1.3 inch OLED 128x64 I2C — main back-face display for status, food results, camera preview, config menu — 30–40 Lei

JST-SH 1.0mm 4-pin connector pair — I2C connection to Pi — 3–5 Lei

Subsystem total: 33–45 Lei

INPUT

Tactile push button with raised cap 6x6mm or 8x8mm — primary user input for logging, menu navigation, calibration — 2–5 Lei

10kΩ resistor — button pull-down to GPIO — less than 1 Lei

Subsystem total: 2–6 Lei

CAMERA AND FOOD ANALYSIS

OV9712 or equivalent ultrawide USB UVC module 100 degree plus FOV — food photo capture and live display preview — 45–90 Lei

Micro-USB OTG right-angle adapter — connects USB camera to Pi Zero USB port — 5–10 Lei

Flat ribbon USB cable 15cm — internal routing from OTG adapter to camera, keeps enclosure tidy — 8–15 Lei

Subsystem total: 58–115 Lei

POWER AND CHARGING

USB-C breakout board 5V — charging port on device short edge — 15–25 Lei

XT30 male and female connector pair — inline quick-swap connector in power cable for fast power bank swapping — 8–12 Lei

Coiled USB-C cable 15cm resting length — connects device to power bank with no loose slack — 12–20 Lei

Subsystem total: 35–57 Lei

INTERNAL WIRING AND CONNECTORS

JST-SH 1.0mm 4-pin connector pairs x3 additional — spare I2C connectors for MPU6050, MAX30102, display runs — 9–15 Lei

24AWG silicone wire 1 meter each in four colors — internal point to point wiring, flexible and heat resistant — 15–25 Lei

Heat shrink tubing assortment — insulation and strain relief on all solder joints — 5–8 Lei

Double-sided foam tape 1mm — mounting boards inside enclosure without screws — 3–5 Lei

Subsystem total: 32–53 Lei

ENCLOSURE AND ASSEMBLY

PETG filament 250g or print service — main device body and clip piece — 30–50 Lei filament or 60–120 Lei print service

TPU filament 100g or print service — soft inner face layer on clip, speaker surround — 20–35 Lei filament or 40–80 Lei print service

M2 screws x8 assorted 4mm and 6mm — case assembly and clip anchor — 3–6 Lei

M2 brass heat-set inserts x8 — screw threads in PETG, far stronger than threading plastic directly — 8–12 Lei

Soldering flux paste small jar — clean joints on fine pitch pads — 5–10 Lei

Subsystem total if printing yourself: 66–118 Lei

Subsystem total if using print service: 116–228 Lei

GRAND TOTAL

Low estimate with own printer: 327–578 Lei

Mid estimate with own printer: roughly 450 Lei

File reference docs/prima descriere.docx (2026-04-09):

Reflux Sentinel — Complete Project Description

What It Is

Reflux Sentinel is a waist-worn smart wearable device designed to help people with acid reflux and GERD manage their condition passively throughout the day and night. It clips onto a belt or waistband, monitors posture continuously, analyzes food before meals via an ultrawide camera, tracks sleep position at night, detects stress via heart rate variability, and delivers spoken and vibration alerts — all running locally on a Raspberry Pi Zero 2 W with no cloud dependency required.

Physical Design & Form Factor

The device is a horizontal slab approximately 80×40×20mm — wider than it is tall, worn landscape orientation on the waistband like a wide belt buckle accessory or a glucose monitor pod. This orientation is more comfortable than vertical for a waist-worn device — it follows the natural curve of the waistband, sits flatter against the body, and the wider front face gives much better placement for both the camera and the speaker without cramming them together.

At under 60g the user stops noticing it within twenty minutes. Hidden completely under an untucked shirt or light jacket.

The full assembly is two pieces: the device body and the clip piece.

Device Body

The inner core containing all electronics. PETG shell, matte finish, 3–4mm rounded corners on every edge and face. No sharp transitions anywhere.

Front face (outward-facing, away from body):

The front face is divided horizontally. The ultrawide camera occupies one end — left or right, user preference when ordering — flush-mounted with a small lens window. The speaker occupies the opposite end with a grille pattern of small holes across roughly a third of the face. The center zone between them is clean and uninterrupted.

Front face (~80×40mm):

┌────────────────────────────────────────────┐

│ [cam] │ │ ~~~ grille ~~~│

│ lens │ (clean) │ ~~~ grille ~~~│

│ │ │ ~~~ grille ~~~│

└────────────────────────────────────────────┘

camera end speaker end

The ultrawide lens — 100°+ FOV — means the user doesn’t need to carefully aim at a plate. A rough point in the direction of the food captures everything on the table in front of them.

Back face (body-facing, under the clip):

The back face has the display and button, both accessed through the clip’s open window. A larger OLED than the typical hobbyist 0.96” — a 1.3” SSD1306 or SH1106 at 128×64px gives noticeably more readable text and a better live camera preview. Display sits center-left on the back face. The button is to the right of the display, raised with a pronounced tactile dome so it can be located by feel without looking.

Back face of device body (~80×40mm, under clip):

┌────────────────────────────────────────────┐

│ ┌─────────────────────┐ [button] │

│ │ 1.3" display │ ← → │

│ │ │ pressable │

│ └─────────────────────┘ │

└────────────────────────────────────────────┘

No LED anywhere on the device. Status is entirely communicated through the display and through vibration or audio.

Clip Piece

A separate printed part that snaps over the back of the device body, inspired directly by the Lamy fountain pen clip — but wide, filled out, and structural rather than a thin metal strip. The clip covers the entire back face and extends slightly beyond the short edges to form the spring blade geometry.

How it works structurally:

One short edge of the clip is the fixed anchor — it hooks over or screws flush into one short edge of the device body. This end doesn’t flex.

The spring blade spans the full back face and bows slightly outward away from the device body in its natural resting state. This bow creates the gap that belt or waistband fabric slides into. The spring tension comes entirely from the geometry of the print — PETG at 2.5–3mm with a deliberate outward curve built into the CAD file. No separate metal spring required.

The ball tip is the opposite short edge — smooth, rounded, the end you press to widen the gap and clip onto a belt. Identical in function to the Lamy ball tip: thumb pressure opens the gap, fabric slides in, release grips. One-handed, two seconds.

The open window is a large rectangular cutout in the center of the clip blade. Sized generously to expose the entire display and the button. The clip frame around the window acts as a protective bezel — the display and button are recessed behind it, shielded from accidental presses and scratches during wear, but completely visible and accessible from behind when the user reaches back to check or press.

The MAX30102 pocket sits on the inner face of the clip, roughly centered. This is the only component on the skin-facing surface. The clip’s natural spring pressure holds the sensor consistently against the body through a thin shirt. A small cutout window in the TPU bumper (see below) ensures direct or near-direct contact. The MAX30102 monitors signal quality programmatically — if no reliable skin contact is detected (thick fabric, jacket), it logs the gap rather than recording garbage HRV data.

Clip piece back view:

╔══════════════════════════════════════════╗ ← fixed anchor edge

║ ║

║ ┌──────────────────────────────────┐ ║

║ │ │ ║ ← open window

║ │ display visible here │ ║ display + button

║ │ [button] │ ║ accessible through

║ │ │ ║ this opening

║ └──────────────────────────────────┘ ║

║ ║

║ [MAX30102 inner face] ║ ← skin contact sensor

║ ║

╚══════════════════════════════════════════╝ ← ball tip edge

↕ spring gap

belt / waistband sits here

Material: Main clip body in PETG for rigidity and spring fatigue resistance. A thin TPU over-layer on the inner face (the skin-facing side) adds grip against clothing so the device doesn’t slide along the waistband, cushions the MAX30102 against the body comfortably, and gives the whole back face a softer feel.

Cable Routing & Charging

The USB-C charging port sits on one of the short edges of the device body — the speaker end makes the most sense, keeping the cable away from the camera end where the user points the device at food. A right-angle USB-C connector keeps the cable profile flush against the body rather than sticking straight out.

Since the device is horizontal on the waistband, the cable from the short edge routes downward into the front pocket naturally. A coiled cable (15cm resting, ~55cm extended) means zero loose slack at any pocket depth.

XT30 quick-swap inline: An XT30 connector pair is spliced into the cable a few centimeters below the device — accessible just by reaching into the top of the pocket. XT30 is a gold-plated locking connector rated for 30A continuous, originally from RC hobby batteries. It clicks together with a positive tactile lock and disconnects with a firm pull. Swapping a depleted power bank for a fresh one takes two seconds without removing the device from the waistband — unclick, swap banks, click in. The device-side pigtail ends in XT30 female and stays permanently attached. The power bank cable ends in XT30 male.

No integrated battery, no BMS circuitry, no charging IC inside the device. Power bank does all of that externally. Keeps the device internals simpler, cooler, and lighter.

Hardware Components

Compute: Raspberry Pi Zero 2 W — quad-core ARM, 512MB RAM, built-in WiFi + Bluetooth 4.2.

Posture & Sleep Sensing: MPU6050 GY-521, 6-axis IMU. Accelerometer gravity vector gives pitch (forward lean for daytime posture) and roll (left/right tilt for sleep position classification). Gyroscope distinguishes genuine sustained slouching from short movement spikes. Mounted flat inside the device body.

Heart Rate & Stress: MAX30102 optical PPG, mounted on the inner face of the clip piece in a flush recessed pocket. Reads pulse and derives HRV as a stress proxy. Beat-to-beat interval variability correlates with autonomic stress state, which is a known GERD trigger. Signal quality checked continuously — gaps in skin contact logged cleanly rather than polluting the data.

Audio: MAX98357A I2S digital amplifier driving a 28–32mm 8Ω 1W speaker on the camera-opposite end of the front face. All voice alerts are pre-generated WAV files produced offline with Piper TTS — no runtime synthesis, near-instant playback. Different alert phrases for different contexts, escalating in directness after repeated events, with per-alert cooldown timers to prevent annoyance.

Silent Alerts: 10mm coin vibration motor. All nighttime nudges, all public-environment alerts, and button press confirmation feedback.

Display: 1.3” OLED — SSD1306 or SH1106, 128×64px, I2C. Larger and more readable than the typical 0.96” module. Sits on the back face of the device body, visible through the clip’s open window. Context-aware display modes for every state the device can be in. Screen blanks after 10 seconds to save power, wakes on button press or when an alert fires.

Camera: OV9712 or equivalent ultrawide USB UVC module, 100°+ field of view, mounted flush on one end of the front face. Completely powered off when idle — USB cameras draw 100–200mA idle, so this matters for battery life. When food analysis mode is triggered, the camera wakes and its live feed streams to the display on the back face as a low-framerate dithered grayscale preview, so the user can see exactly what the camera sees while pointing it at their meal. The ultrawide FOV means precise aiming is unnecessary — a casual point toward the plate captures everything.

Input: Single raised tactile button on the back face, to the right of the display, pressable through the clip window. Short press = symptom log. Two or three presses = severity 2 or 3. Long press = meal log. Double press = enter config menu. Five-second hold = calibration mode.

Internal connectors: JST-SH 1.0mm 4-pin (Qwiic/STEMMA QT standard) for all I2C runs between the Pi and sensor boards — tiny, locking, pre-crimpable, and disconnectable without desoldering. Direct soldered short wires for speaker, vibration motor, and button since these never need to be field-disconnected. Flat ribbon USB cable internally from Pi OTG port to camera to keep routing tidy inside the horizontal enclosure.

Display Modes

Idle / daytime:

┌──────────────────────────────┐

│ POSTURE: GOOD ✓ 14:32 │

│ Risk: ████░░░░ LOW │

│ Last meal: 1h 23m ago │

│ HRV: normal │

└──────────────────────────────┘

Post-meal countdown:

┌──────────────────────────────┐

│ ⚠ STAY UPRIGHT │

│ Since meal: 47 min │

│ Safe at: 16:15 │

│ Food risk: HIGH │

└──────────────────────────────┘

Food analysis — live camera preview:

Display switches to a dithered grayscale live feed from the ultrawide camera at 5–10fps. User watches the display to frame their shot, presses button to capture. After inference:

┌──────────────────────────────┐

│ DETECTED: ORANGE JUICE │

│ Risk: HIGH ACID │

│ Stay upright: 2–3 hrs │

│ Confidence: 87% │

└──────────────────────────────┘

Spoken advice plays simultaneously through the speaker.

Sleep mode:

┌──────────────────────────────┐

│ SLEEP MODE │

│ Position: LEFT SIDE ✓ │

│ Duration: 2h 14m │

│ Score: 91 / 100 │

└──────────────────────────────┘

Config menu:

┌──────────────────────────────┐

│ > WEAR SIDE: LEFT │

│ SENSITIVITY: MEDIUM │

│ SLEEP TIME: 23:00 │

│ CALIBRATE... │

└──────────────────────────────┘

Posture Monitoring

MPU6050 reads at 2Hz baseline, bumping to 5Hz for two hours after a meal is logged. A rolling ring buffer of recent readings means alerts only fire after 60+ continuous seconds of bad posture — not on momentary dips. The gyroscope filters out movement spikes so bending to pick something up doesn’t trigger a false alert.

On first boot or calibration reset, the user holds the button through a guided OLED sequence: stand upright and hold to record the personal zero angle, lean slightly forward and hold to record the slouch reference, lie on the left side and hold to record the sleep reference. Every subsequent reading is relative to these personal values — the device’s physical mounting angle doesn’t matter at all.

Contextual thresholds: the acceptable posture angle becomes stricter for two hours after a high-risk meal than at baseline. Risk level is a composite of current pitch angle, time since last meal, and the food risk score from the last camera analysis.

Food Analysis Pipeline

Long press → camera mode

→ Camera wakes

→ Live ultrawide feed appears on back display

→ User frames shot by watching display

→ Short press to capture

→ Frame resized to 224×224

→ TFLite MobileNetV2 inference (~5–10 seconds)

→ Top-3 labels mapped to risk dictionary (100+ foods)

→ Result shown on display

→ Spoken advice plays through speaker

→ Event logged to SQLite with timestamp and risk score

→ Camera powers off

If confidence is below 60%, the device says it can’t identify the food and prompts manual logging rather than guessing wrong. The risk dictionary is a plain Python dict editable through the web app — users can add personal trigger foods and override risk levels.

Sleep Tracking

When pitch flattens to near-horizontal and stays there with minimal movement for 10+ minutes during the configured sleep window (default 11pm–7am), the device automatically switches to sleep mode. No user action required.

In sleep mode: sample rate drops to once every 30 seconds, speaker goes completely silent, all alerts become vibration-only.

Roll angle maps directly to sleep position: approximately 90° to the left = good, 90° to the right = bad, near 0° = back sleeping (bad), inverted pitch = front sleeping (worst). If the user sustains a bad position for more than 10 minutes, the device sends a single gentle 500ms vibration pulse. If uncorrected after 5 minutes, a second slightly stronger double pulse. After three attempts on the same event it gives up and logs silently — disrupted sleep is itself a GERD trigger and the device shouldn’t make that worse.

Maximum three nudge events per night total regardless of position. Every position change is timestamped in the sleep log.

Morning Telegram summary: percentage of time in each position, quality score out of 100, nudge count and whether they resulted in correction, and a contextual tip based on the worst period of the night.

Optional night pod for users who find the waist clip uncomfortable in bed: a tiny secondary unit (ESP32-C3 + MPU6050 + vibration motor) worn on a soft wrist or ankle elastic strap, syncing data to the main unit via BLE in the morning while the main device charges.

Wear Position Calibration & Configuration

Double press → config menu navigable with single presses, confirmed with hold. Wear side cycles LEFT / CENTER / RIGHT — this affects how roll angles map to sleep positions and how forward tilt is interpreted for posture, since the device’s orientation relative to the body differs depending on hip placement.

Full 5-second-hold calibration runs the guided OLED sequence for personal angle references. These are stored in config.json and persist across reboots.

Connectivity

Bluetooth LE (always available): Pi’s built-in BT 4.2 runs a BLE peripheral via the bleak Python library. The companion app connects as central. Real-time posture data pushed as notifications. Config synced phone to device. SQLite events offloaded to phone for backup and dashboard display. Works anywhere with no network required — primary communication method when away from home WiFi.

Flask web UI (via Tailscale over WiFi): Full dashboard served from the Pi, accessible globally via Tailscale — same setup as the user’s existing server infrastructure. Live posture display refreshing every 5 seconds, today’s event timeline, settings page with all configuration, sleep history charts, food log with captured thumbnails, and reports page. Config changes write to config.json and hot-reload into the running process via the watchdog library without restarting.

Telegram bot: Daily morning sleep summaries pushed automatically. Weekly pattern reports every Sunday. Alert echoes for significant events. User can send commands back: /log meal, /log symptom, /status, /report. Pi initiates all outbound connections — works behind any NAT, no open ports required.

Flask Web App Structure

web/

├── app.py

└── templates/

├── base.html

├── dashboard.html live posture, timeline, quick-log buttons

├── settings.html all config, food risk table editor, calibration

├── sleep.html per-night position chart, history, nudge log

├── food_log.html camera analyses with thumbnails, manual entry

└── reports.html weekly summary, CSV/JSON export, doctor link

Live sensor values flow from the main process to Flask via a Unix socket. Config changes flow the other way via config.json watched by watchdog. The shareable doctor link generates a read-only token-gated URL exporting a clean formatted summary of the user’s recent data.

Code Architecture

Event-driven throughout — no tight polling loops. A lightweight scheduler wakes components only when needed. Systemd managed with Restart=on-failure. CPU governor set to powersave by default, bumped only during TFLite inference. SQLite in WAL mode, writes batched every 30 seconds rather than per-event. Camera fully powered off between uses.

reflux_sentinel/

├── main.py entry point, thread orchestration

├── config.py constants, pin numbers, thresholds, paths

├── sensor.py MPU6050 reads, angle calc, activity detection

├── sleep_tracker.py position classification, nudge logic, morning report

├── mode_manager.py day / sleep / camera mode switching

├── alerts.py cooldown, escalation, audio + vibration

├── logger.py SQLite WAL wrapper, batch write queue

├── camera.py capture, dither→display preview, TFLite, risk lookup

├── button.py GPIO interrupt handler, menu state machine

├── foods.py risk dictionary 100+ entries

├── ble_server.py BLE peripheral, GATT characteristics

├── web/

│ ├── app.py

│ └── templates/

└── audio/ pre-generated WAVs via Piper TTS

Full Hardware List & Cost

|Component |Purpose |Est. Lei |

|MPU6050 GY-521 |Posture + sleep position|23–35 |

|MAX30102 |HRV / stress detection |25–40 |

|MAX98357A I2S amp |Drives speaker |30–57 |

|Speaker 28–32mm 8Ω 1W |Voice output |8–20 |

|Coin vibration motor 10mm |Silent nudges |5–10 |

|SSD1306 / SH1106 1.3” OLED |Back display |30–40 |

|Tactile button raised cap |Primary input |2–5 |

|10kΩ resistor |Button pull-down |<1 |

|OV9712 ultrawide USB UVC |Food camera |45–90 |

|Micro-USB OTG right-angle |Camera connection |5–10 |

|Flat ribbon USB cable 15cm |Internal routing |8–15 |

|USB-C breakout board |Charging port |15–25 |

|XT30 connector pair |Quick-swap inline |8–12 |

|Coiled USB-C cable 15cm rest |Power bank connection |12–20 |

|JST-SH 1.0mm 4-pin ×6 pairs |I2C board connectors |15–25 |

|24AWG silicone wire assorted |Internal wiring |15–25 |

|Heat shrink assortment |Insulation |5–8 |

|PETG filament 250g |Main enclosure + clip |30–50 |

|TPU filament 100g |Clip inner face bumper |20–35 |

|M2 screws ×8 + heat-set inserts ×8|Assembly |11–18 |

|Acoustic mesh fabric |Speaker grille cover |2–5 |

|Double-sided foam tape 1mm |Internal mounting |3–5 |

|**Total** | |**~366–600 Lei**|

Realistic mid-range build: ~500 Lei. Parts sourced from Quintrix and Adelaida Impex in Craiova for in-person pickup, remainder from AliExpress.

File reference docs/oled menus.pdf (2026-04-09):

# Reflux Sentinel — OLED Menu Reference

### Display: SSD1306 / SH1106 1.3” OLED · 128×64 px · Monochrome white-on-black

Controls: Rotary encoder (scroll / click) top-right · Tactile button (back / action) top-left

### Mount: Back face of device, visible through PETG clip window

# Legend

┌──────────────────────────────┐ │ ◄ = back button (top-left) │ │ ► = encoder click (confirm) │ │ ↕ = encoder scroll (navigate)│
│ ▶ = selected / active item | │
│ ░ = progress / fill bar | │
└──────────────────────────────┘

# 1 · First Boot — Onboarding Flow

## 1.1 Welcome Screen

┌────────────────────────────┐
│ | | │
│ | ██████ ██████ ██████ | │
│ | REFLUX SENTINEL | │
│ | | │
│ | Wearable GERD Monitor | │
│ | | │
│ | ► Press encoder to start │
└────────────────────────────┘

## 1.2 Wear-Side Selection

┌────────────────────────────┐
│ SETUP: Wear Side | │
│ ────────────────────── | │

│ | | │
│ ▶ Left side | │
│ | Right side | │
│ | | │
│ Clip faces outward | │
└────────────────────────────┘

## 1.3 Calibration Prompt

┌────────────────────────────┐
│ SETUP: Calibrate Posture | │
│ ────────────────────── | │
│ | | │
│ Stand upright & still | │
│ | | │
│ ► Click to capture | │
│ | baseline posture | │
└────────────────────────────┘

## 1.4 Calibration Complete

┌────────────────────────────┐
│ | | │
│ | ✓ Calibrated! | │
│ | | │
│ Baseline saved | │
│ Pitch: 0.0° | │
│ | | │
│ Starting in 3s... | │
└────────────────────────────┘

## 1.5 Hotspot QR Code

┌────────────────────────────┐
│ Wi-Fi Setup | │
│ ───────────────────────── │
│ ▓▓▓▓ ▓ ▓ ▓▓▓▓ | │
│ ▓ ▓ ▓▓▓▓ ▓ ▓ Scan to │
│ ▓▓▓▓ ▓ ▓ ▓▓▓▓ connect │
│ ▓ ▓ ▓▓ ▓ ▓ ▓ | │
│ Sentinel-AP / 192.168.1.1 │ └────────────────────────────┘

QR encodes SSID + WPA2 password for one-tap phone join.

# 2 · Normal Operation — Watch Face (Home)

## 2.1 Default Watch Face

┌────────────────────────────┐ │ 14:32 ●GOOD ♥ 68bpm │
│ ───────────────────────── │ │ Posture: ████████░░ 82% │
│ Pitch: | -3.2° | │
│ | | │
│ Last meal: 1h 24m ago | │
│ Upright ✓ Next log: hold │ └────────────────────────────┘

## 2.2 Watch Face — Alert State

┌────────────────────────────┐ │ 14:35 ▲SLOUCH ♥ 71bpm │
│ ───────────────────────── │ │ Posture: ████░░░░░░ 42% │
│ Pitch: | -18.4° ← lean! │
│ | │
│ Straighten up | │
│ [■■■■■■■■░░] Alert lvl 2 │ └────────────────────────────┘

## 2.3 Watch Face — Post-Meal Countdown

┌────────────────────────────┐
│ 15:10 ●GOOD ♥ 65bpm │
│ ───────────────────────── │ │ Posture: ██████████ 94% │
│ | | │
│ | Stay upright: 1h 36m | │
│ [████████████░░░░] 73% | │
│ Meal logged at 13:34 | │
└────────────────────────────┘

# 3 · Main Menu

Reached by a single encoder click from the watch face.

┌────────────────────────────┐
│ ≡ MAIN MENU | │
│ ───────────────────────── │
│ ▶ Log Meal | │
│ | Log Symptom | │
│ | Medication | │
│ | Settings | │
│ | Sleep Mode | │
│ | About | │
└────────────────────────────┘

# 4 · Meal Logging Flow

## 4.1 Log Meal — Confirm

┌────────────────────────────┐
│ LOG MEAL | | │
│ ───────────────────────── │
│ | | │
│ Log meal now? | │
│ Time: 15:10 | │
│ | | │
│ ▶ Yes | No | │
└────────────────────────────┘

## 4.2 Food Photo Capture

┌────────────────────────────┐
│ FOOD PHOTO | │
│ ───────────────────────── │
│ | | │
│ Point camera at food | │
│ | | │
│ ► Click to capture | │
│ | Skip photo | │
└────────────────────────────┘

## 4.3 Analysing Food

┌────────────────────────────┐
│ ANALYSING... | │
│ ───────────────────────── │
│ | | │
│ | [████████████░░░░] | │
│ | Running TFLite model | │
│ | | │
│ | Please wait... | │
└────────────────────────────┘

## 4.4 Food Result — Low Risk

┌────────────────────────────┐
│ FOOD ANALYSIS | | │
│ ───────────────────────── │
│ Detected: Salad / Veg | │
│ Risk: ● LOW | | │
│ | | │
│ Good choice! Stay upright │
│ for 2h after eating. | │
│ ► Confirm | Retry | │
└────────────────────────────┘

## 4.5 Food Result — High Risk

┌────────────────────────────┐
│ FOOD ANALYSIS | | │
│ ───────────────────────── │
│ Detected: Pizza / Fatty | │
│ Risk: ▲ HIGH | | │
│ | | │
│ Stay upright 3h. Avoid | │
│ lying down. Eat smaller | │
│ ► Confirm | Retry | │
└────────────────────────────┘

## 4.6 Meal Saved

┌────────────────────────────┐

│ | ✓ Meal Logged | │

│ Upright timer started: | │
│ Stay upright for 2h 30m | │
│ | │
│ Returning to watch face | │
└────────────────────────────┘

# 5 · Symptom Logging

## 5.1 Symptom Severity

┌────────────────────────────┐
│ LOG SYMPTOM | │
│ ───────────────────────── │
│ Severity? | │
│ | | │
│ ▶ 1 – Mild | │
│ | 2 – Moderate | │
│ | 3 – Severe | │
└────────────────────────────┘

## 5.2 Symptom Type

┌────────────────────────────┐
│ SYMPTOM TYPE | │
│ ───────────────────────── │
│ ▶ Heartburn | │
│ | Regurgitation | │
│ | Bloating | │
│ | Chest pain | │
│ | Other | │
└────────────────────────────┘

## 5.3 Symptom Saved

┌────────────────────────────┐
│ | | │
│ | ✓ Symptom Logged | │
│ | | │
│ Severity: 2 – Moderate | │
│ Type: Heartburn | │

│ Time: 15:14 | │

└────────────────────────────┘

# 6 · Medication

## 6.1 Medication Reminder (auto popup)

┌────────────────────────────┐
│ | MEDICATION REMINDER | │
│ ───────────────────────── │
│ | | │
│ Omeprazole 20mg | │
│ Scheduled: 20:00 | │
│ | | │
│ ► Tap button to confirm | │
└────────────────────────────┘

## 6.2 Medication Acknowledged

┌────────────────────────────┐
│ | | │
│ | ✓ Med Acknowledged | │
│ | | │
│ Omeprazole 20mg | │
│ Taken at: 20:03 | │
│ | | │
│ | | │
└────────────────────────────┘

## 6.3 Medication List (from menu)

┌────────────────────────────┐
│ MEDICATIONS | │
│ ───────────────────────── │
│ ▶ Omeprazole 20:00 ✓ | │
│ | Gaviscon | 22:00 … | │
│ | | | │
│ | (Configure on phone) | │
│ | ◄ Back | | │
└────────────────────────────┘

# 7 · Settings Menu

## 7.1 Settings Root

┌────────────────────────────┐
│ ⚙ SETTINGS | │
│ ───────────────────────── │
│ ▶ Wear Side | │
│ | Calibrate | │
│ | Hotspot | │
│ | Sleep Window | │
│ | Nudge Config | │
│ | ◄ Back | │
└────────────────────────────┘

## 7.2 Wear Side

┌────────────────────────────┐
│ WEAR SIDE | │
│ ───────────────────────── │
│ Current: LEFT | │
│ | | │
│ ▶ Left side | │
│ | Right side | │
│ | | │
│ ◄ Back | │
└────────────────────────────┘

## 7.3 Recalibrate Posture — Prompt

┌────────────────────────────┐
│ RECALIBRATE | | │
│ ───────────────────────── │
│ | | │
│ Stand upright & still | │
│ Device clipped on | │
│ | | │
│ ▶ Start | Cancel | │
└────────────────────────────┘

## 7.3b Recalibrate — Countdown

┌────────────────────────────┐
│ RECALIBRATE | │
│ ───────────────────────── │
│ Hold still... | │
│ | │
│ [████████████░░░░] | │
│ Capturing in 2s... | │
│ | │
└────────────────────────────┘

## 7.3c Recalibrate — Done

┌────────────────────────────┐
│ | | │
│ | ✓ Baseline Saved | │
│ | | │
│ Pitch offset: -1.2° | │
│ 04 Apr 09:15 | │
│ | | │
│ (Visible in phone app) | │
└────────────────────────────┘

## 7.4 Hotspot Settings — ON

┌────────────────────────────┐
│ HOTSPOT | │
│ ───────────────────────── │
│ Status: ● ON | │
│ 192.168.1.1 | │
│ Connected: 1 phone | │
│ ▶ Turn Off | │
│ | Set Schedule Show QR | │
└────────────────────────────┘

## 7.4b Hotspot Settings — OFF

┌────────────────────────────┐
│ HOTSPOT | │
│ ───────────────────────── │
│ Status: ○ OFF | │
│ Sched ON at: 07:00 | │

│ ▶ Turn On Now | │
│ | Set Schedule | │
└────────────────────────────┘

## 7.4c Hotspot Toggled (transient overlay)

┌────────────────────────────┐
│ | | │
│ | Hotspot is ON | │
│ | 192.168.1.1 | │
│ | Sentinel-AP | │
│ | | │
│ | (auto-dismiss 3s) | │
└────────────────────────────┘

## 7.5 Hotspot Schedule

┌────────────────────────────┐
│ HOTSPOT SCHEDULE | │
│ ───────────────────────── │
│ ▶ Mode: Scheduled | │
│ | ON at: | 07:00 | │
│ | OFF at: 23:00 | │
│ | | | │
│ ► Click to edit · ◄ Back │ └────────────────────────────┘

## 7.5b Schedule Edit (encoder scrolls hour/min)

┌────────────────────────────┐
│ SET ON TIME | │
│ ───────────────────────── │
│ | | | │
│ | [ 07 ] : [ 00 ] | │
│ | ↕ | ↕ | │
│ | scroll | scroll | │
│ | | | │
│ ► Confirm | ◄ Cancel | │
└────────────────────────────┘

## 7.6 Sleep Window

┌────────────────────────────┐
│ SLEEP WINDOW | │
│ ───────────────────────── │
│ Auto-detect: ON | │
│ From: 23:00 | │
│ Until: 07:00 | │
│ | │
│ (Edit on phone PWA) | │
│ ◄ Back | │
└────────────────────────────┘

## 7.7 Nudge Config

┌────────────────────────────┐
│ NUDGE CONFIG | │
│ ───────────────────────── │
│ Day haptics: ● ON | │
│ Night haptics:● ON (max 3) │
│ Voice alerts: ● ON | │
│ | │
│ (Edit thresholds on phone) │
│ ◄ Back | │
└────────────────────────────┘

# 8 · Sleep Mode

## 8.1 Sleep Mode — Auto Detect

┌────────────────────────────┐
│ | SLEEP MODE | │
│ ───────────────────────── │
│ Detected: lying flat | │
│ Roll: +12° (Right side) | │
│ | | │
│ Position: ▲ NOT IDEAL | │
│ Try: left side sleep | │
└────────────────────────────┘

## 8.2 Sleep Mode — Good Position

┌────────────────────────────┐
│ | SLEEP MODE | │
│ ───────────────────────── │
│ Roll: -22° (Left side) | │
│ | | │
│ Position: ● GOOD | │
│ Monitoring... 0.03Hz | │
│ Nudges tonight: 0/3 | │
└────────────────────────────┘

## 8.3 Sleep Mode — Grace Period

┌────────────────────────────┐
│ | SLEEP MODE | │
│ ───────────────────────── │
│ Lying down detected | │
│ | | │
│ Grace period: 1m 42s left │
│ [█████████░░░░░░] | │
│ Monitoring posture... | │
└────────────────────────────┘

# 9 · About Screen

┌────────────────────────────┐
│ ABOUT | │
│ ───────────────────────── │
│ Reflux Sentinel v0.1 | │
│ RPi Zero 2 W | │
│ | │
│ Local-only · No cloud | │
│ Made in Craiova, RO | │
│ ◄ Back | │
└────────────────────────────┘

# 10 · Transient Overlays (non-navigable)

## 10.1 Hydration Reminder

┌────────────────────────────┐

│ | Hydration Reminder | │
│ | | │
│ Time to drink some water! │
│ | | │
│ ► OK | (auto-dismiss 5s) │
└────────────────────────────┘

## 10.2 Hotspot Connected

┌────────────────────────────┐
│ | | │
│ | Phone Connected | │
│ | | │
│ 192.168.1.1 | │
│ Auto-backup running... | │
│ | | │
└────────────────────────────┘

## 10.3 Low Power Warning

┌────────────────────────────┐
│ | | │
│ | Power Bank Low | │
│ | | │
│ Charge soon | │
│ | | │
│ (auto-dismiss) | │
└────────────────────────────┘

# OLED Navigation Map

┌─────────────────┐
│ | ONBOARDING | │
│ (first boot only│
└────────┬────────┘
│ complete
| ▼
┌──────────────────────────┐
│ | WATCH FACE | │ ◄──────────────────────┐

│ (posture · HRV · time) │ | │
└────────────┬─────────────┘ | │
encoder click │ | │
▼ | │
┌──────────────────────────┐ | │
│ | MAIN MENU | │ | │
└┬──────┬──────┬───┬───┬──┘ | │
│ | │ | │ | │ | │ | │
▼ | ▼ | ▼ | ▼ | ▼ | │
LOG | LOG | MEDS SETTINGS SLEEP | │
MEAL | SYMPTOM | MODE | │
│ | │ | │ | │
▼ | ▼ | ┌────────┴──────────┐ | │
photo | severity | auto-detected | manual enter | │
scan | / type | from IMU data | │
│ | │ | │
└────────┴────────────────────────────────────────────┘
| | | | saved / back

### All OLED screens render at 128×64 px. Font: 1× and 2× scale system font. Invert highlight

used for selected items. Screens auto-return to watch face after 30s inactivity.

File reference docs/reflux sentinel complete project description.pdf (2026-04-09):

# Reflux Sentinel — Complete Project Description

Compiled April 4, 2026 — synthesised from all project conversations, memories, and design decisions

## 1. What It Is

Reflux Sentinel is a wearable GERD (gastroesophageal reflux disease) monitoring device designed for people managing chronic acid reflux. It clips to the waist, tracks posture, sleep position, meals, symptoms, and heart rate variability, and delivers real-time audio and haptic feedback when it detects risky behaviour — such as lying down too soon after eating, or sleeping on the wrong side.

The device is fully offline and air-gapped. It never connects to the internet. Communication with the user’s phone happens exclusively over a local WiFi hotspot the device broadcasts. All data stays on-device in a SQLite database, synced to the phone only when the user explicitly connects.

The creator, David, is based in Craiova, Romania, and sources parts locally from Quintrix, Adelaida Impex, and Altex, supplemented by AliExpress for harder-to-find components. The total parts budget for the prototype is approximately 550–600 Lei.

## 2. Design Philosophy

Every decision flows from a few core principles:

Compact and discreet. The device must be comfortable for all-day wear on a belt or waistband, hard to notice under clothing, and light enough that the user forgets it’s there within 20 minutes. Target weight is under 60g for the clip unit alone.

Fully offline. No cloud, no internet, no Telegram, no BLE — ever. The Pi broadcasts its own WiFi hotspot. The device never joins any external network. This was a deliberate architectural decision, not a limitation. It eliminates dependency on external services, simplifies the software stack, and keeps health data entirely under the user’s control.

No internal battery. Power comes from the user’s existing 10,000 mAh power bank in a pocket, connected via a short USB-C cable with an XT30 inline quick-swap connector. This keeps the clip unit thin and light, avoids LiPo BMS complexity, and gives effectively unlimited runtime.

No mic, no LED. Audio is output-only (speaker + vibration motor). No always-listening microphone, no status LEDs. The OLED display on the back face handles all visual feedback.

Event-driven, not polling. The software architecture reacts to state changes rather than continuously sampling. This keeps CPU usage minimal, thermals low, and power draw manageable on the Pi Zero 2 W’s single-core ARM.

## 3. Hardware Specification (Locked)

3.1 Platform

Raspberry Pi Zero 2 W — quad-core ARM Cortex-A53, 512MB RAM, built-in WiFi (used for hotspot), built-in Bluetooth (unused — disabled). Runs Raspberry Pi OS Lite. All development in Python.

3.2 Form Factor

Horizontal slab, approximately 80mm × 40mm × 20mm. Comparable in size to a thick pager or a glucose monitor. Matte finish PETG enclosure with 3–4mm radius on all corners and edges for comfort. Monolithic shell — no visible screws on front or sides.

Front face (faces outward when worn):

OV9712 ultrawide USB UVC camera at one end — for food photo capture

Speaker grilles at the opposite end — patterned holes for the 28–32mm speaker

Top edge:

Tactile button on the left — primary action/back button

EC11 rotary encoder with push-click on the right — scroll/select/confirm (“crown”); 10nF capacitors for hardware debounce

Back face (faces the body, visible through clip window):

SSD1306 1.3” or SH1106 OLED display, centred — shows status, menus, QR codes, food results, onboarding

Display and encoder/button are accessible through an open window in the clip

Clip mechanism:

Lamy-style PETG blade that curves over the back of the device body

An open window in the clip exposes the OLED display and controls

The clip grips belt/waistband fabric between the blade and the device body

PETG chosen for flexibility and fatigue resistance over PLA

Inner face of clip (against skin):

MAX30102 optical heart rate sensor — pressed against skin by the clip’s tension

Small foam pad behind the MAX30102 for consistent contact pressure

Signal quality indicator read programmatically; HRV pauses automatically when no skin contact detected

3.3 Power System

Source: User’s existing 10,000 mAh power bank, kept in a pocket

Connection: Short USB-C cable from power bank to the device’s USB-C port on the short edge

Quick-swap: XT30 inline connector on the cable — robust click-lock, allows instant battery swap without shutting down (capacitor hold-up on the Pi side)

No internal battery, no LiPo, no BMS

3.4 Sensors & Output

Component | Model | Purpose | Interface | Location
IMU | MPU6050 GY-521 | Posture (pitch/roll), gyro activity, sleep position | I2C (GPIO 2/3) | Inside enclosure
HRV sensor | MAX30102 | Heart rate variability, stress correlation | I2C | Clip inner face
Audio amp | MAX98357A | Drives speaker for voice alerts | I2S | Inside enclosure
Speaker | 28–32mm 8Ω 1W | Voice output (pre-generated WAV files) | Wired to amp | Front face
Vibration | Coin type | Haptic nudges (silent alerts, | GPIO + | Inside

motor | | sleep) | transistor | enclosure
Display | SSD1306 1.3” / SH1106 | Status, menus, food results, QR code | I2C | Back face
Camera | OV9712 USB UVC | Food photo capture for TFLite analysis | USB OTG | Front face
Action button | Tactile switch | Primary action, back, meal/symptom logging | GPIO interrupt | Top left
Rotary encoder | EC11 with click | Scroll, select, confirm | GPIO (3 pins) | Top right

Wiring approach: Direct point-to-point GPIO wiring. No breadboard. Headers desoldered from breakout boards to minimise height. Short wires routed through internal cable channels moulded into the PETG case walls.

## 4. Connectivity Architecture

4.1 WiFi Hotspot (Only Network Interface)

The Pi runs hostapd and broadcasts its own WiFi network. The device never joins any external network. When the user wants to sync data, view dashboards, or change settings, they connect their phone to the device’s hotspot.

Max clients: 1–2 simultaneous connections

Hotspot control: User sets on/off schedule hours via the phone PWA, or toggles manually from the device’s OLED/encoder

QR code: The OLED can display a QR code encoding the hotspot SSID and password — one scan on iOS 13+ or Android 10+ auto-joins the network, no typing

Access point IP: 192.168.1.1 — the Flask PWA lives here

4.2 What Was Removed (and Why)

BLE — removed entirely. Adds protocol complexity, library dependencies (bleak), and pairing headaches. WiFi hotspot handles everything BLE would do, with higher bandwidth and zero pairing friction.

Tailscale — removed. Required internet access, which contradicts the air-gapped

design.

Telegram bot — removed. Required internet access. Morning reports and notifications now appear on the Flask dashboard when the phone connects.

Cloud backend — removed from prototype. Reserved for Stage 2/3 scaling.

## 5. Software Architecture

5.1 Core Principles

Event-driven: Modules communicate through an internal event bus (Python queue). No module calls another directly. mode_manager.py is the sole consumer that orchestrates state transitions.

systemd-managed: Main process runs as a systemd service with Restart=on-failure . Automatic recovery from crashes.

Hot-reloadable config: config.json watched via Python watchdog library. Changes from the phone PWA take effect immediately without restart.

CPU governor: powersave by default, temporarily bumped during TFLite inference only.

5.2 Module Structure

reflux_sentinel/
├── main.py | # Entry point, signal handling, event bus setup, systemd integration
├── config.py | # Loads/watches config.json, provides typed access to all settings
├── imu.py | # MPU6050 — pitch/roll/gyro reads, posture angle, activity detection
├── hrv.py | # MAX30102 — HRV calculation, signal quality check, skin contact detection
├── alerts.py | # WAV playback (MAX98357A), vibration motor patterns, cooldown tracking
├── logger.py | # SQLite wrapper — WAL mode, batch writes every 30s, schema management
├── camera.py | # OV9712 capture, powers camera on/off, feeds frames to foods.py
├── button.py | # GPIO interrupt handler for tactile button — press patterns, long press
├── encoder.py | # EC11 rotary encoder — rotation events, click events, debounce logic
├── foods.py | # TFLite MobileNetV2 inference, food risk dictionary (100+ entries), result formatting
├── sleep_tracker.py | # Sleep position classification, nudge scheduling, morning report generation
├── mode_manager.py | # Central FSM — orchestrates all state transitions, consumes event bus
├── hotspot.py | # hostapd management — bring up/tear down, monitor connections, trigger auto-backup
├── meds.py | # Medication reminder timers — fires alerts, tracks acknowledgment
├── web/
│ | ├── app.py | # Flask PWA server — all routes, API endpoints, WebSocket for live data
│ | └── templates/ | # Jinja2 templates for dashboard, settings, reports, onboarding
└── audio/ | # Pre-generated WAV files via Piper TTS — all voice alerts stored here

5.3 Database (SQLite with WAL)

Tables:

sessions — device power-on/off events, wear-side, calibration baseline

events — meals, symptoms (severity 1–3), food photos, medication acknowledgments

posture_log — timestamped pitch/roll/activity, sparse (logged on state change, not continuously)

sleep_log — sleep position samples, nudge events, morning summary data

Write strategy: Batch writes every 30 seconds. State-change logging only — not continuous time-series. This keeps I/O manageable on the Pi Zero’s SD card.

Calibration persistence: Personal calibration baselines stored in SQLite (not just config.json), surviving reboots and config resets.

5.4 Sensor Sampling Rates

Baseline: 2 Hz (MPU6050 pitch/roll)

Post-meal window (2–3 hours): 5 Hz

Sleep mode: 0.03 Hz (one sample every ~33 seconds)

Camera: Fully powered off until triggered by user action; draws 0mA when off

## 6. Finite State Machine (mode_manager.py)

The FSM has 8 states with explicit transitions:

6.1 States

State | Description
BOOTING | Hardware init, sensor checks, config load, display splash
ONBOARDING | First-boot flow — language, wear side, calibration, sleep window
IDLE | Normal monitoring — posture tracking at 2Hz, alerts active

Triggered by meal log — elevated sampling (5Hz), stricter posture

POST_MEAL | thresholds, meal countdown timer active
FOOD_PHOTO | Camera active, TFLite inference running, result shown on OLED, awaiting crown click confirmation
PRE_SLEEP | Transitional — pitch flat detected, 10-minute stillness countdown before entering full sleep
SLEEPING | Ultra-low-power monitoring — 0.03Hz sampling, vibration-only nudges, position classification
CALIBRATING | User-initiated recalibration of posture baseline via OLED + encoder

6.2 Key Transition Rules

POST_MEAL blocks sleep entry — cannot transition to PRE_SLEEP while meal countdown is active

FOOD_PHOTO is gated — only accessible from POST_MEAL or IDLE, not during sleep states

PRE_SLEEP requires all three conditions: pitch flat + 10 minutes of stillness + time within sleep window (default 11pm–7am, configurable)

Medication reminders queue during FOOD_PHOTO and CALIBRATING states rather than interrupting

Lying-down grace period: 2 minutes of escalating haptic warnings before voice alert fires (prevents false alarms from briefly sitting down)

6.3 Edge Cases Sealed

Sleep cannot activate mid-meal (POST_MEAL blocks it)

Camera cannot fire in wrong state (gated by FSM)

Config changes during TFLite inference are deferred

Double food photo triggers prevented (camera state locked during inference)

Power bank disconnect recovery (capacitor hold-up, graceful shutdown write)

Hotspot dying mid-sync (auto-retry with backoff)
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

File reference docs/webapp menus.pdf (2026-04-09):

# Reflux Sentinel — Companion Web App (PWA) Reference

### Access: Connect phone to Sentinel-AP Wi-Fi · Open http://192.168.1.1 Platform: Flask PWA · iOS + Android · Install prompt on first visit Connectivity: Local hotspot only — no internet, no cloud, no external access Max connections: 1–2 phones simultaneously

# Navigation Structure

┌──────────────────────────────────────────────────────────────┐
│ Bottom Nav Bar (persistent) | │
│ [ | Dashboard] [ | Food Log] [ | Sleep] [ | Reports] [⚙ Settings] │
└──────────────────────────────────────────────────────────────┘

# 1 · First Visit — Install Prompt

╔══════════════════════════════════════════╗
║ | | | ║
║ | Reflux Sentinel | | ║
║ | Companion App | | ║
║ | | | ║
║ Add to your Home Screen for the | ║
║ best experience. | ║
║ | | | ║
║ ┌──────────────────────────────────┐ | ║
║ │ | Add to Home Screen | │ | ║
║ └──────────────────────────────────┘ | ║
║ ┌──────────────────────────────────┐ | ║
║ │ | Continue in Browser | │ | ║
║ └──────────────────────────────────┘ | ║
║ | | | ║
╚══════════════════════════════════════════╝

### Platform detected: shows native iOS share-sheet instructions or Android “Add to Home

Screen” prompt.

# 2 · Dashboard (Home)
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

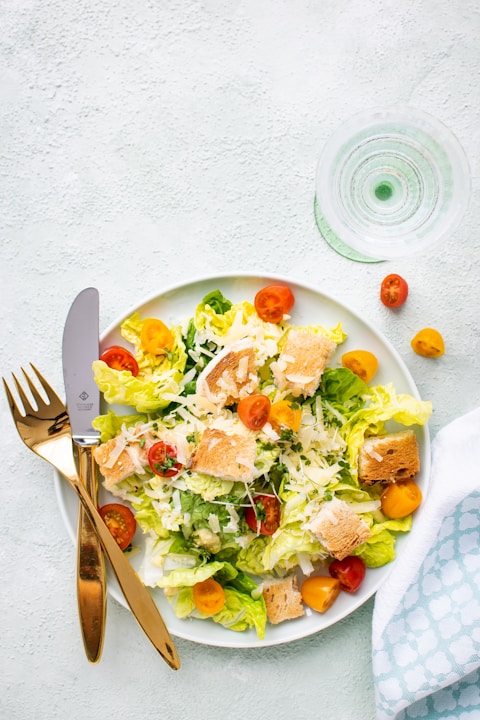
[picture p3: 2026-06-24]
simulator/scripts/food_fixtures/caesar_salad.jpg

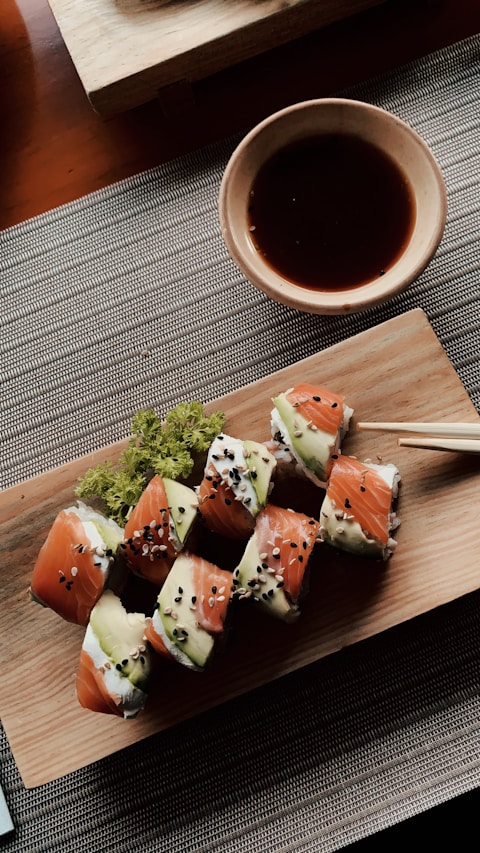
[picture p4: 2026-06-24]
simulator/scripts/food_fixtures/sushi.jpg

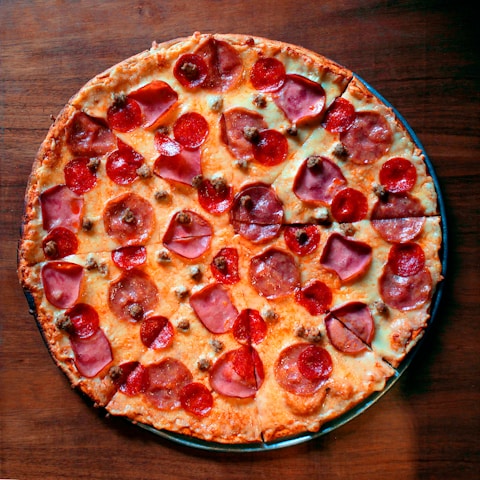
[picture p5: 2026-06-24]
simulator/scripts/food_fixtures/pepperoni_pizza.jpg

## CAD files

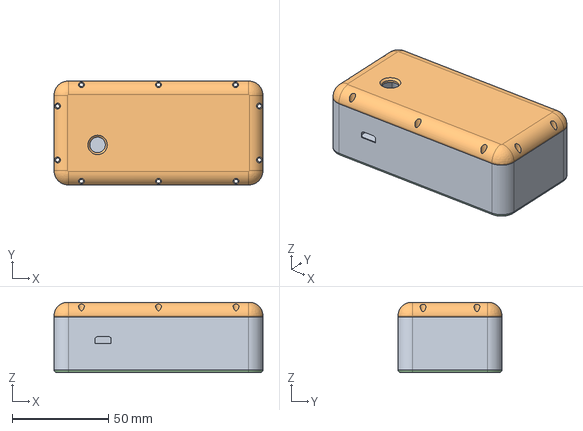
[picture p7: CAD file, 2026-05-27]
cad/fullassembly.step
108.5 x 54.0 x 36.5 mm

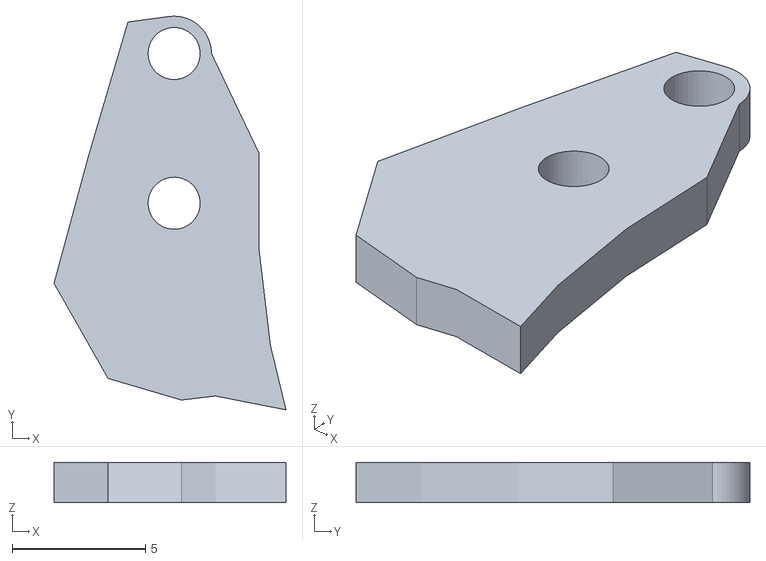
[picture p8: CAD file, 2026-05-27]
cad/camera mount.stl
8.69 x 14.7 x 1.50

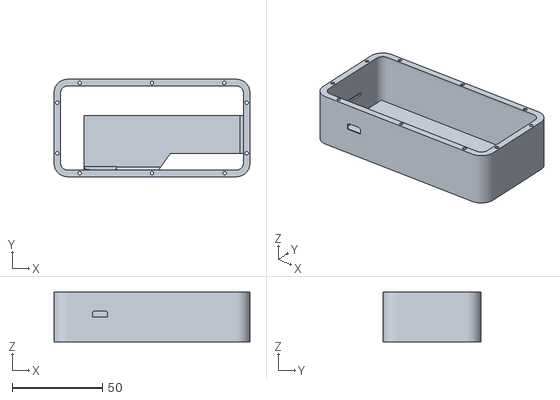
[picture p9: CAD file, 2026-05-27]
cad/center piece.stl
108.5 x 54.0 x 27.5

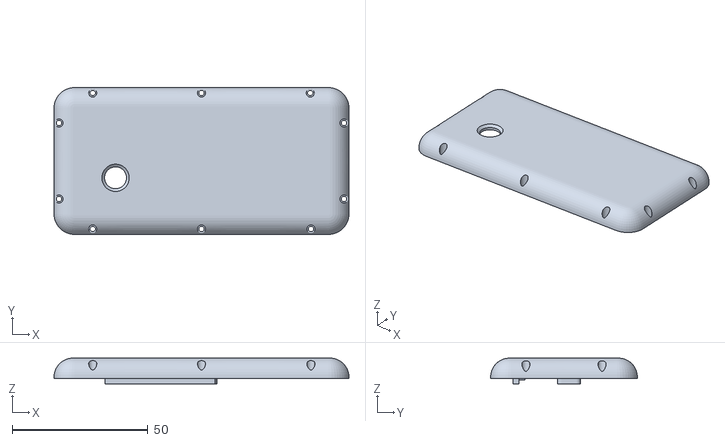
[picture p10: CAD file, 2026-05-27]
cad/cover.stl
108.5 x 54.0 x 9.50

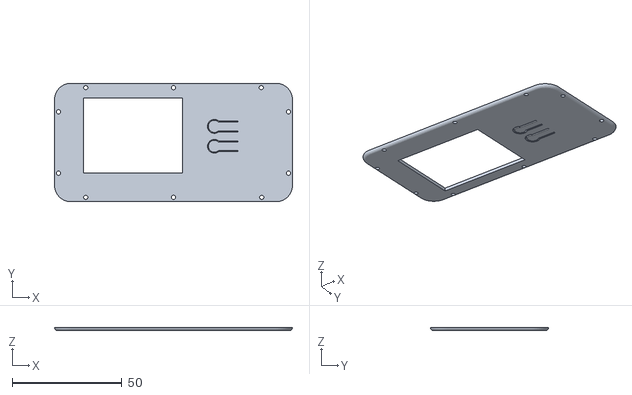
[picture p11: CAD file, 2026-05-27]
cad/displaycover.stl
108.5 x 54.0 x 1.50

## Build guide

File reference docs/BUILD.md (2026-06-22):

# Build & bring-up

## Bill of materials (summary)

| Role | Part |
|---|---|
| MCU | Raspberry Pi Zero 2 W |
| IMU | MPU6050 (GY-521) |
| HRV / pulse | MAX30102 |
| Display | 1.3" SH1106 or SSD1306 128×64 OLED |
| Audio amp | MAX98357A I²S |
| Speaker | 28–32 mm 8 Ω 1 W |
| Vibration motor | 10 mm coin, 3 V |
| Motor driver | 2N2222 + 1N4001 flyback diode |
| Camera | OV9712 USB UVC module |
| Input | Tactile button + EC11 rotary encoder |
| Power | External 10 000 mAh USB-C power bank |

See [`WIRING.md`](WIRING.md) for the exact pinout.

## Flashing the Pi

1. Raspberry Pi OS Lite (64-bit, bookworm or later).
2. In `rpi-imager` advanced options: enable SSH, set hostname `upright`,
   preload your home WiFi credentials.
3. Boot the Pi, SSH in, then:

```bash
curl -fsSL https://raw.githubusercontent.com/david-constantinescu/gerd/main/install.sh | bash
sudo reboot
```

## Bring-up order

Wire one sensor at a time, validate with the matching script, then move on.

```bash
# Sanity check — should list 0x3C (OLED), 0x68 (MPU6050), 0x57 (MAX30102)
python3 firmware/scripts/i2c_scan.py

# OLED
python3 firmware/scripts/oled_hello.py

# IMU
python3 firmware/scripts/imu_dump.py

# HRV
python3 firmware/scripts/hrv_dump.py

# Button (GPIO 4)
python3 firmware/scripts/button_test.py

# Encoder (GPIO 17/27/22) — 10 nF caps are MANDATORY on CLK/DT
python3 firmware/scripts/encoder_test.py

# Vibration motor (GPIO 5 via 2N2222)
python3 firmware/scripts/motor_test.py

# I²S audio amp
python3 firmware/scripts/play_test_wav.py

# USB camera
python3 firmware/scripts/camera_test.py
```

Once every script passes, start the full firmware loop:

```bash
sudo systemctl restart upright upright-web
journalctl -u upright -f
```

## Power

The device has no internal battery on purpose. A short coiled USB-C cable
connects it to a 10 000 mAh power bank in a nearby pocket, with an XT30
quick-swap connector so you can rotate banks without rebooting the Pi.

Expected runtime on a single 10 Ah bank:

| Mode | Draw | Runtime |
|---|---|---|
| IDLE, Wi-Fi client | ~130 mA | ~65 h |
| IDLE, hosting setup AP | ~200 mA | ~42 h |
| SLEEPING (0.03 Hz IMU) | ~80 mA | ~106 h |
| Food photo burst | ~500 mA | ~15 s / capture |

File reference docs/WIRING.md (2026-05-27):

# Wiring — Pi Zero 2 W pinout

The canonical source is `reference docs/reflux sentinel wiring diagram.pdf`.
Condensed version:

## I²C — MPU6050 (accelerometer / posture)

Firmware bit-bang I²C (preferred — no kernel overlay). **Do not use GPIO 28 for
SCL on Pi Zero 2 W**; that line is reserved for SDIO and will report `GPIO busy`.

| Signal | Pi pin (BCM) | Header pin | Notes |
|---|---|---|---|
| SDA | GPIO **27**  | 13 | firmware bit-bang |
| SCL | GPIO **3** | 5 | not GPIO 28 |
| INT | GPIO **13**  | 21 | optional; firmware polls |
| VCC | 3V3 | 1 or 17 | |
| GND | GND | 6, 9, 14…  | |

Add **4.7 kΩ pull-ups** on SDA and SCL to 3.3 V if the breakout has none.
After wiring, reboot and check logs for `MPU6050 bit-bang … WHO_AM_I ok`.

## I²C bus (shared — MAX30102, OLED) — optional / not on this build

| Signal | Pi pin (BCM) | Notes |
|---|---|---|
| SDA | GPIO 2 | pull-up already on every breakout |
| SCL | GPIO 3 | |
| VCC | 3V3 | all three devices are 3.3 V |
| GND | GND | |

Expected `i2cdetect -y 1` output: `0x3C`, `0x57`, `0x68`.

## I²S audio (MAX98357A)

| Signal | Pi pin (BCM) |
|---|---|
| BCLK | GPIO 18 |
| LRCLK  | GPIO 19 |
| DIN | GPIO 21 |
| VIN | 5V |
| GND | GND |
| GAIN | GND (9 dB) |
| SD | VIN |

Enable I²S in `/boot/firmware/config.txt`:

```
dtparam=i2s=on
dtoverlay=hifiberry-dac
```

## Direct GPIO

| Device | Pin (BCM) | Notes |
|---|---|---|
| Button A (back) | 20 | active low, internal pull-up |
| Button B (menu) | 21 | active low, internal pull-up |
| Vibration motor | 22 | physical pin 15 (motor IN) |
| LiPo alert | 4 | Pimoroni Zero LiPo (active low) |

No rotary encoder on this build. UI controls: see `oled-mockups.md`.

## USB camera

OV9712 connects via USB OTG. Use a right-angle micro-USB adapter; power is
drawn through the OTG port when the firmware turns the camera on.

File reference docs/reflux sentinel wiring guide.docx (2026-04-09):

REFLUX SENTINEL

Wiring & Assembly Guide

Raspberry Pi Zero 2 W • GPIO Pinout • Component Connections

Rev 1.0 — April 2026

# 1. Overview

This document covers every physical connection in the Reflux Sentinel prototype. All components connect directly to the Raspberry Pi Zero 2 W via point-to-point wiring — no breadboard, no shield, no PCB. Headers are desoldered from all breakout boards (MPU6050, MAX30102, MAX98357A, SSD1306) and wires are soldered directly to board pads for minimum height.

The device uses three communication buses: I²C (shared by three sensors/display), I²S (audio amplifier), and USB (camera). The remaining connections are simple GPIO digital lines for the button, rotary encoder, and vibration motor.

# 2. I²C Bus — Address Map

All three I²C devices share GPIO2 (SDA, Pin 3) and GPIO3 (SCL, Pin 5). There are no address conflicts — each device has a unique address on the bus.

Device | I²C Address | Notes
MPU6050 | 0x68 | AD0 pin low (default). Pull AD0 high for 0x69 if second unit needed.
MAX30102 | 0x57 | Fixed address, no conflicts possible.
SSD1306 | 0x3C | Some modules use 0x3D; check with i2cdetect. Most 1.3" units are 0x3C.

Verification command after assembly: i2cdetect -y 1. Expected output should show devices at 0x3C, 0x57, and 0x68.

# 3. Complete GPIO Pinout Table

The Pi Zero 2 W has a 40-pin GPIO header. Reflux Sentinel uses 10 GPIO pins, 2 power pins, and the USB OTG port. 16 GPIO pins remain unused and available for future expansion.

Pin # | GPIO | Function | Connected To
1 | — | 3.3V Power | MPU6050 VCC, MAX30102 VCC, SSD1306 VCC, Motor VCC
2 | — | 5V Power | MAX98357A VIN
3 | GPIO2 | I²C SDA | MPU6050 SDA + MAX30102 SDA + SSD1306 SDA
5 | GPIO3 | I²C SCL | MPU6050 SCL + MAX30102 SCL + SSD1306 SCL
6 | — | Ground | Common ground for all components
7 | GPIO4 | Button input | Tactile button → GND (internal pull-up enabled)
9 | — | Ground | Button GND, Encoder GND
11 | GPIO17 | Encoder CLK | EC11 CLK pin + 10nF cap to GND
12 | GPIO18 | I²S BCLK | MAX98357A BCLK
13 | GPIO27 | Encoder DT | EC11 DT pin + 10nF cap to GND
14 | — | Ground | MAX98357A GND, Motor GND (via transistor)
15 | GPIO22 | Encoder SW | EC11 push-switch (internal pull-up)
29 | GPIO5 | Motor drive | → 1kΩ resistor → 2N2222 base
35 | GPIO19 | I²S LRCLK | MAX98357A LRC
40 | GPIO21 | I²S DIN | MAX98357A DIN
USB | OTG | USB device port | OV9712 camera via flat ribbon + right-angle adapter

# 4. Component Wiring Details

## 4.1 MPU6050 GY-521 (IMU)

Location: inside enclosure, flat against the Pi board. Orientation matters — the chip’s X-axis should align with the device’s vertical axis (pitch = forward/backward tilt).

MPU6050 Pin | Pi Pin | Notes
VCC | Pin 1 (3V3) | 3.3V supply
GND | Pin 6 (GND) | Common ground
SDA | Pin 3 (GPIO2) | I²C data
SCL | Pin 5 (GPIO3) | I²C clock
AD0 | Leave unconnected | Floats low = addr 0x68
INT | Not connected | Polling used, not interrupts

## 4.2 MAX30102 (HRV Sensor)

Location: clip inner face, pressed against skin. Small foam pad behind the board for consistent contact pressure. Wire routing runs along the clip blade edge from the sensor to the main board inside the enclosure.

MAX30102 Pin | Pi Pin | Notes
VIN | Pin 1 (3V3) | 3.3V supply
GND | Pin 6 (GND) | Common ground
SDA | Pin 3 (GPIO2) | Shared I²C bus
SCL | Pin 5 (GPIO3) | Shared I²C bus
INT | Not connected | Software polls signal quality

## 4.3 SSD1306 / SH1106 OLED Display

Location: back face, centered, visible through the clip window. 1.3” monochrome 128×64. I²C version (4 pins), not SPI.

OLED Pin | Pi Pin | Notes
VCC | Pin 1 (3V3) | 3.3V supply
GND | Pin 6 (GND) | Common ground
SDA | Pin 3 (GPIO2) | Shared I²C bus
SCL | Pin 5 (GPIO3) | Shared I²C bus

## 4.4 MAX98357A I²S Amplifier

Location: inside enclosure, near the speaker. Needs 5V supply (not 3.3V) for adequate speaker drive power. The GAIN pin should be tied to GND for 9dB gain (reasonable for a small speaker at close range). The SD (shutdown) pin should be tied to VIN to keep the amp always enabled — the software controls audio by simply not sending I²S data when silent.

MAX98357A Pin | Pi Pin | Notes
VIN | Pin 2 (5V) | 5V supply
GND | Pin 14 (GND) | Common ground
BCLK | Pin 12 (GPIO18) | I²S bit clock
LRC | Pin 35 (GPIO19) | I²S word select
DIN | Pin 40 (GPIO21) | I²S data
GAIN | Tie to GND | 9dB gain
SD | Tie to VIN | Always enabled

Speaker connection: Bare tinned wire soldered from the MAX98357A’s + and – output pads directly to the 28–32mm 8Ω 1W speaker terminals. No connector needed. Keep wires short (3–5cm) to minimize EMI pickup.

## 4.5 Tactile Button

Location: top-left edge of enclosure, flush-mounted. One leg connects to GPIO4 (Pin 7), the other to GND (Pin 9). The Pi’s internal pull-up resistor is enabled in software, so no external resistor is needed. The GPIO reads HIGH normally and goes LOW on press.

Timing thresholds (implemented in button.py):

Action | Duration | Function
Single press | < 400ms release | Mild symptom (severity 1)
Double press | 2 presses within 500ms | Moderate symptom (severity 2)
Triple press | 3 presses within 500ms | Severe symptom (severity 3)
Long press | Hold 1.5s – 3s | Log meal event
Very long press | Hold ≥ 3s | Enter calibration mode

## 4.6 EC11 Rotary Encoder

Location: top-right edge. Functions as the “crown” for scrolling menus and confirming selections. The encoder has 5 pins: CLK, DT, SW (push-click), and two GND pins (one for rotation, one for switch).

EC11 Pin | Pi Pin | Notes
CLK | Pin 11 (GPIO17) | + 10nF ceramic cap to GND
DT | Pin 13 (GPIO27) | + 10nF ceramic cap to GND
SW | Pin 15 (GPIO22) | Internal pull-up enabled
GND (rotation) | Pin 9 (GND) | Encoder common
GND (switch) | Pin 9 (GND) | Switch common

Critical: The 10nF debounce capacitors on CLK and DT are mandatory. Without them, the encoder generates phantom steps and direction reversals. Solder the caps as close to the encoder pins as possible, with the other leg to the nearest GND.

## 4.7 Coin Vibration Motor

Location: inside enclosure. Cannot be driven directly from a GPIO pin (motors draw 80–100mA; GPIO max is 16mA). Requires a transistor driver circuit:

1. GPIO5 (Pin 29) connects through a 1kΩ resistor to the base of a 2N2222 NPN transistor.
2. Transistor collector connects to the motor’s negative terminal.
3. Transistor emitter connects to GND (Pin 14).
4. Motor’s positive terminal connects to 3.3V (Pin 1).
5. 1N4001 flyback diode across the motor terminals: cathode (stripe) to positive, anode to negative. Protects the transistor from back-EMF when the motor switches off.

Schematic:

GPIO5 → [1kΩ] → Base ┌─ 2N2222 ─┐ Collector → Motor(–) → Motor(+) → 3V3

│ Emitter → GND

1N4001 diode across motor: cathode at Motor(+)

## 4.8 OV9712 USB Camera

Location: front face, one end. This is the only USB device. It connects to the Pi’s micro-USB OTG port via a flat ribbon-style USB cable (not a round cable) routed along one internal wall of the enclosure. A right-angle micro-USB OTG adapter keeps the connector low-profile.

The camera draws 100–200mA when active but is powered off entirely by software when not in use (0mA). It is only activated when the user enters FOOD_PHOTO state.

## 4.9 Power System

The 10,000 mAh power bank sits in the user’s pocket, connected by a short USB-C cable to the device’s USB-C power port on the short edge. An XT30 inline connector on the cable provides quick-swap capability — the user can swap banks without shutting down (a small hold-up capacitor on the Pi side bridges the gap).

# 5. Power Budget

Component | Current | Notes
Pi Zero 2 W (idle, WiFi off) | ~100 mA | powersave governor, BT disabled
Pi Zero 2 W (hotspot active) | ~170 mA | hostapd running, 1–2 clients
MPU6050 @ 2Hz | ~3.5 mA | Always on during wake states
MAX30102 (active) | ~5 mA | Intermittent — only on skin contact
SSD1306 OLED | ~20 mA | Typical; varies with pixel fill
MAX98357A (quiescent) | ~2 mA | No I²S signal = near-silent draw
MAX98357A (playing audio) | ~50–100 mA | Only during 3–15s alert playback
OV9712 camera (active) | ~100–200 mA | Only during food photo (~10s)
OV9712 camera (off) | 0 mA | Powered off by software
Coin motor (buzzing) | ~80 mA | Sub-second pulses only

### Estimated Battery Life

Mode | Draw | Runtime (10Ah @ 85%)
Daytime (monitoring, OLED, no hotspot) | ~130 mA | ~65 hours (2.7 days)
Daytime + hotspot active | ~200 mA | ~42 hours (1.8 days)
Peak (TFLite + hotspot + audio) | ~450–550 mA | 15–20 seconds per food photo
Sleep mode (0.03Hz, OLED off) | ~80 mA | ~106 hours (4.4 days)

Bottom line for the clinic: Charges once every 2–3 days with normal use. Power bank is hot-swappable via XT30 connector without powering down.

# 6. Failure Modes & Recovery

Failure | Detection | Recovery
MPU6050 I²C error | 3 consecutive IOError over 5s | OLED: “IMU offline”, haptic buzz, retry every 30s. Posture monitoring paused.
MAX30102 garbage | RMSSD outside 5–300ms for 10 reads | HRV pauses silently, gap logged. Non-critical — no user alert.
Camera timeout | No frame captured within 10s | OLED: “Camera error — try again.” Returns to prior FSM state. After 3 failures: “Check camera connection.”
SQLite corruption | PRAGMA integrity_check fails on boot | Attempt restore from auto-backup. If none, rename corrupt DB, create fresh, OLED: “Database reset.”
Process crash | systemd detects exit | Restart=on-failure, RestartSec=5, WatchdogSec=60
Power bank disconnect | Voltage drop / capacitor depleting | Capacitor hold-up for graceful shutdown write to SQLite
Hotspot dies mid-sync | Connection lost during backup | Auto-retry with exponential backoff

# 7. Recommended Assembly Order

Follow this order to avoid rework and to test each subsystem incrementally:

6. Desolder all pin headers from MPU6050, MAX30102, MAX98357A, and SSD1306 breakout boards. Use solder wick or a desoldering pump.
7. Wire the I²C bus first. Connect MPU6050 to Pi (4 wires: VCC, GND, SDA, SCL). Power on and run i2cdetect -y 1 to confirm 0x68 appears.
8. Add SSD1306 OLED to the same I²C bus (just 4 more solder points to the same lines). Run i2cdetect again — should see 0x3C and 0x68. Test with a quick Python script to display text.
9. Add MAX30102 to I²C bus. i2cdetect should now show 0x3C, 0x57, 0x68. All three on one bus, confirmed.
10. Wire the tactile button (GPIO4 to one leg, GND to the other). Test with a simple GPIO read script.
11. Wire the EC11 encoder (3 data pins + GND). Solder the 10nF caps. Test rotation direction and click with a test script before committing to the enclosure.
12. Wire the MAX98357A (5 wires: VIN, GND, BCLK, LRC, DIN + GAIN/SD ties). Connect speaker. Test with aplay and a WAV file.
13. Build the motor driver circuit (transistor, resistor, diode). Test by toggling GPIO5.
14. Connect OV9712 camera via USB OTG. Test with a capture command (fswebcam or OpenCV). This is the last component because USB cable routing is enclosure-dependent.
15. Final integration test: Run i2cdetect (3 addresses), aplay (audio), capture a photo, toggle motor, read button and encoder. All working = ready for enclosure.

# 8. Notes on Headers & Height

Every breakout board ships with tall through-hole pin headers (~8mm). Removing these and soldering wires directly to the pads saves 8mm of height per board. This is essential for fitting everything in the 20mm-deep enclosure. The Pi Zero 2 W itself can use its castellated pads on the bottom edge instead of the 40-pin header, saving another 8mm. Total height savings: ~16mm, which is the difference between “fits in the case” and “doesn’t.”

Boards to desolder headers from: MPU6050 GY-521, MAX30102 breakout, MAX98357A, SSD1306/SH1106 OLED module, and optionally the Pi Zero 2 W itself (use castellated pads instead of header).

Reflux Sentinel — Wiring & Assembly Guide

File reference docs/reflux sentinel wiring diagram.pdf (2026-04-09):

<svg xmlns="http://www.w3.org/2000/svg" viewBox="0 0 1400 1050" font-family="'Segoe UI', Arial, sans-serif"> <defs>
<style>
.pin-label { font-size: 10px; fill: #333; }
.pin-num { font-size: 9px; fill: #888; font-weight: bold; } .component-title { font-size: 14px; fill: #fff; font-weight: bold; } .component-detail { font-size: 10px; fill: #e0e0e0; }
.wire-i2c { stroke: #2196F3; stroke-width: 2.5; fill: none; } .wire-i2s { stroke: #9C27B0; stroke-width: 2.5; fill: none; } .wire-gpio { stroke: #4CAF50; stroke-width: 2.5; fill: none; } .wire-power { stroke: #F44336; stroke-width: 2.5; fill: none; } .wire-gnd { stroke: #333; stroke-width: 2.5; fill: none; }
.wire-usb { stroke: #FF9800; stroke-width: 2.5; fill: none; }
.legend-text { font-size: 11px; fill: #333; }
.section-label { font-size: 12px; fill: #666; font-weight: bold; text-transform: uppercase; letter-spacing: 1px; } .note-text { font-size: 10px; fill: #555; }
.addr-text { font-size: 9px; fill: #FFD54F; font-weight: bold; }
</style>
<marker id="arrowBlue" markerWidth="8" markerHeight="6" refX="8" refY="3" orient="auto"> <polygon points="0 0, 8 3, 0 6" fill="#2196F3"/>
</marker>
<marker id="arrowPurple" markerWidth="8" markerHeight="6" refX="8" refY="3" orient="auto"> <polygon points="0 0, 8 3, 0 6" fill="#9C27B0"/>
</marker>
<marker id="arrowGreen" markerWidth="8" markerHeight="6" refX="8" refY="3" orient="auto"> <polygon points="0 0, 8 3, 0 6" fill="#4CAF50"/>
</marker>
<marker id="arrowRed" markerWidth="8" markerHeight="6" refX="8" refY="3" orient="auto"> <polygon points="0 0, 8 3, 0 6" fill="#F44336"/>
</marker>
<marker id="arrowOrange" markerWidth="8" markerHeight="6" refX="8" refY="3" orient="auto"> <polygon points="0 0, 8 3, 0 6" fill="#FF9800"/>
</marker>
<marker id="arrowBlack" markerWidth="8" markerHeight="6" refX="8" refY="3" orient="auto"> <polygon points="0 0, 8 3, 0 6" fill="#333"/>
</marker>
</defs>

<!-- Background -->
<rect width="1400" height="1050" fill="#FAFAFA" rx="8"/>

<!-- Title -->
<text x="700" y="35" text-anchor="middle" font-size="20" font-weight="bold" fill="#1a1a1a">Reflux Sentinel — GPIO Wiring Diagram</text> <text x="700" y="55" text-anchor="middle" font-size="12" fill="#777">Raspberry Pi Zero 2 W

<!-- ==================== PI ZERO 2 W BOARD ==================== -->
<g transform="translate(420, 90)">
<!-- Board outline -->
<rect x="0" y="0" width="300" height="560" rx="8" fill="#2E7D32" stroke="#1B5E20" stroke-width="2"/> <rect x="10" y="10" width="280" height="540" rx="4" fill="#388E3C" opacity="0.5"/>

<!-- Board title -->
<text x="150" y="35" text-anchor="middle" font-size="16" font-weight="bold" fill="#fff">Raspberry Pi Zero 2 W</text> <text x="150" y="52" text-anchor="middle" font-size="10" fill="#A5D6A7">BCM2710

<!-- USB OTG port -->
<rect x="105" y="530" width="50" height="22" rx="3" fill="#555" stroke="#333" stroke-width="1"/> <text x="130" y="545" text-anchor="middle" font-size="8" fill="#fff">USB OTG</text>

<!-- USB Power port -->
<rect x="175" y="530" width="50" height="22" rx="3" fill="#555" stroke="#333" stroke-width="1"/> <text x="200" y="545" text-anchor="middle" font-size="8" fill="#fff">USB PWR</text>

<!-- CSI camera connector (unused) -->
<rect x="120" y="495" width="60" height="10" rx="2" fill="#444" stroke="#333"/>
<text x="150" y="520" text-anchor="middle" font-size="7" fill="#81C784">CSI (unused)</text>

<!-- GPIO Header - Left column (odd pins: 1,3,5,...,39) -->
<!-- Pin 1: 3.3V -->
<circle cx="55" cy="85" r="6" fill="#F44336" stroke="#C62828" stroke-width="1.5"/> <text x="45" y="89" text-anchor="end" class="pin-label">3V3</text>
<text x="55" y="79" text-anchor="middle" class="pin-num">1</text>

<!-- Pin 3: GPIO2 (SDA) -->
<circle cx="55" cy="110" r="6" fill="#2196F3" stroke="#1565C0" stroke-width="1.5"/> <text x="45" y="114" text-anchor="end" class="pin-label">SDA1</text>
<text x="55" y="104" text-anchor="middle" class="pin-num">3</text>

<!-- Pin 5: GPIO3 (SCL) -->
<circle cx="55" cy="135" r="6" fill="#2196F3" stroke="#1565C0" stroke-width="1.5"/> <text x="45" y="139" text-anchor="end" class="pin-label">SCL1</text>
<text x="55" y="129" text-anchor="middle" class="pin-num">5</text>

<!-- Pin 7: GPIO4 -->
<circle cx="55" cy="160" r="6" fill="#4CAF50" stroke="#2E7D32" stroke-width="1.5"/> <text x="45" y="164" text-anchor="end" class="pin-label">GPIO4</text>
<text x="55" y="154" text-anchor="middle" class="pin-num">7</text>

<!-- Pin 9: GND -->
<circle cx="55" cy="185" r="6" fill="#333" stroke="#111" stroke-width="1.5"/> <text x="45" y="189" text-anchor="end" class="pin-label">GND</text>

<text x="55" y="179" text-anchor="middle" class="pin-num">9</text>

<!-- Pin 11: GPIO17 -->
<circle cx="55" cy="210" r="6" fill="#4CAF50" stroke="#2E7D32" stroke-width="1.5"/> <text x="45" y="214" text-anchor="end" class="pin-label">GPIO17</text>
<text x="55" y="204" text-anchor="middle" class="pin-num">11</text>

<!-- Pin 13: GPIO27 -->
<circle cx="55" cy="235" r="6" fill="#4CAF50" stroke="#2E7D32" stroke-width="1.5"/> <text x="45" y="239" text-anchor="end" class="pin-label">GPIO27</text>
<text x="55" y="229" text-anchor="middle" class="pin-num">13</text>

<!-- Pin 15: GPIO22 -->
<circle cx="55" cy="260" r="6" fill="#4CAF50" stroke="#2E7D32" stroke-width="1.5"/> <text x="45" y="264" text-anchor="end" class="pin-label">GPIO22</text>
<text x="55" y="254" text-anchor="middle" class="pin-num">15</text>

<!-- Pin 17: 3.3V -->
<circle cx="55" cy="285" r="6" fill="#F44336" stroke="#C62828" stroke-width="1.5"/> <text x="45" y="289" text-anchor="end" class="pin-label">3V3</text>
<text x="55" y="279" text-anchor="middle" class="pin-num">17</text>

<!-- Pin 19: GPIO10 (MOSI) -->
<circle cx="55" cy="310" r="6" fill="#757575" stroke="#424242" stroke-width="1.5"/> <text x="45" y="314" text-anchor="end" class="pin-label">MOSI</text>
<text x="55" y="304" text-anchor="middle" class="pin-num">19</text>

<!-- Pin 21: GPIO9 (MISO) -->
<circle cx="55" cy="335" r="6" fill="#757575" stroke="#424242" stroke-width="1.5"/> <text x="45" y="339" text-anchor="end" class="pin-label">MISO</text>
<text x="55" y="329" text-anchor="middle" class="pin-num">21</text>

<!-- Pin 23: GPIO11 (SCLK) -->
<circle cx="55" cy="360" r="6" fill="#757575" stroke="#424242" stroke-width="1.5"/> <text x="45" y="364" text-anchor="end" class="pin-label">SCLK</text>
<text x="55" y="354" text-anchor="middle" class="pin-num">23</text>

<!-- Pin 25: GND -->
<circle cx="55" cy="385" r="6" fill="#333" stroke="#111" stroke-width="1.5"/> <text x="45" y="389" text-anchor="end" class="pin-label">GND</text>
<text x="55" y="379" text-anchor="middle" class="pin-num">25</text>

<!-- Pin 27: GPIO0 (ID_SD) -->
<circle cx="55" cy="410" r="6" fill="#757575" stroke="#424242" stroke-width="1.5"/> <text x="45" y="414" text-anchor="end" class="pin-label">ID_SD</text>
<text x="55" y="404" text-anchor="middle" class="pin-num">27</text>

<!-- Pin 29: GPIO5 -->
<circle cx="55" cy="435" r="6" fill="#4CAF50" stroke="#2E7D32" stroke-width="1.5"/> <text x="45" y="439" text-anchor="end" class="pin-label">GPIO5</text>
<text x="55" y="429" text-anchor="middle" class="pin-num">29</text>

<!-- Pin 31: GPIO6 -->
<circle cx="55" cy="460" r="6" fill="#757575" stroke="#424242" stroke-width="1.5"/> <text x="45" y="464" text-anchor="end" class="pin-label">GPIO6</text>
<text x="55" y="454" text-anchor="middle" class="pin-num">31</text>

<!-- Pin 33: GPIO13 -->
<circle cx="55" cy="485" r="6" fill="#757575" stroke="#424242" stroke-width="1.5"/> <text x="45" y="489" text-anchor="end" class="pin-label">GPIO13</text>
<text x="55" y="479" text-anchor="middle" class="pin-num">33</text>

<!-- GPIO Header - Right column (even pins: 2,4,6,...,40) -->
<!-- Pin 2: 5V -->
<circle cx="85" cy="85" r="6" fill="#D32F2F" stroke="#B71C1C" stroke-width="1.5"/> <text x="95" y="89" text-anchor="start" class="pin-label">5V</text>
<text x="85" y="79" text-anchor="middle" class="pin-num">2</text>

<!-- Pin 4: 5V -->
<circle cx="85" cy="110" r="6" fill="#D32F2F" stroke="#B71C1C" stroke-width="1.5"/> <text x="95" y="114" text-anchor="start" class="pin-label">5V</text>
<text x="85" y="104" text-anchor="middle" class="pin-num">4</text>

<!-- Pin 6: GND -->
<circle cx="85" cy="135" r="6" fill="#333" stroke="#111" stroke-width="1.5"/> <text x="95" y="139" text-anchor="start" class="pin-label">GND</text>
<text x="85" y="129" text-anchor="middle" class="pin-num">6</text>

<!-- Pin 8: GPIO14 (TXD) -->
<circle cx="85" cy="160" r="6" fill="#757575" stroke="#424242" stroke-width="1.5"/> <text x="95" y="164" text-anchor="start" class="pin-label">TXD</text>
<text x="85" y="154" text-anchor="middle" class="pin-num">8</text>

<!-- Pin 10: GPIO15 (RXD) -->
<circle cx="85" cy="185" r="6" fill="#757575" stroke="#424242" stroke-width="1.5"/> <text x="95" y="189" text-anchor="start" class="pin-label">RXD</text>
<text x="85" y="179" text-anchor="middle" class="pin-num">10</text>

<!-- Pin 12: GPIO18 (PCM_CLK / I2S BCLK) -->
<circle cx="85" cy="210" r="6" fill="#9C27B0" stroke="#6A1B9A" stroke-width="1.5"/> <text x="95" y="214" text-anchor="start" class="pin-label">GPIO18</text>
<text x="85" y="204" text-anchor="middle" class="pin-num">12</text>

<!-- Pin 14: GND -->

<circle cx="85" cy="235" r="6" fill="#333" stroke="#111" stroke-width="1.5"/> <text x="95" y="239" text-anchor="start" class="pin-label">GND</text>
<text x="85" y="229" text-anchor="middle" class="pin-num">14</text>

<!-- Pin 16: GPIO23 -->
<circle cx="85" cy="260" r="6" fill="#4CAF50" stroke="#2E7D32" stroke-width="1.5"/> <text x="95" y="264" text-anchor="start" class="pin-label">GPIO23</text>
<text x="85" y="254" text-anchor="middle" class="pin-num">16</text>

<!-- Pin 18: GPIO24 -->
<circle cx="85" cy="285" r="6" fill="#4CAF50" stroke="#2E7D32" stroke-width="1.5"/> <text x="95" y="289" text-anchor="start" class="pin-label">GPIO24</text>
<text x="85" y="279" text-anchor="middle" class="pin-num">18</text>

<!-- Pin 20: GND -->
<circle cx="85" cy="310" r="6" fill="#333" stroke="#111" stroke-width="1.5"/> <text x="95" y="314" text-anchor="start" class="pin-label">GND</text>
<text x="85" y="304" text-anchor="middle" class="pin-num">20</text>

<!-- Pin 22: GPIO25 -->
<circle cx="85" cy="335" r="6" fill="#4CAF50" stroke="#2E7D32" stroke-width="1.5"/> <text x="95" y="339" text-anchor="start" class="pin-label">GPIO25</text>
<text x="85" y="329" text-anchor="middle" class="pin-num">22</text>

<!-- Pin 24: GPIO8 (CE0) -->
<circle cx="85" cy="360" r="6" fill="#757575" stroke="#424242" stroke-width="1.5"/> <text x="95" y="364" text-anchor="start" class="pin-label">CE0</text>
<text x="85" y="354" text-anchor="middle" class="pin-num">24</text>

<!-- Pin 26: GPIO7 (CE1) -->
<circle cx="85" cy="385" r="6" fill="#757575" stroke="#424242" stroke-width="1.5"/> <text x="95" y="389" text-anchor="start" class="pin-label">CE1</text>
<text x="85" y="379" text-anchor="middle" class="pin-num">26</text>

<!-- Pin 28: GPIO1 (ID_SC) -->
<circle cx="85" cy="410" r="6" fill="#757575" stroke="#424242" stroke-width="1.5"/> <text x="95" y="414" text-anchor="start" class="pin-label">ID_SC</text>
<text x="85" y="404" text-anchor="middle" class="pin-num">28</text>

<!-- Pin 30: GND -->
<circle cx="85" cy="435" r="6" fill="#333" stroke="#111" stroke-width="1.5"/> <text x="95" y="439" text-anchor="start" class="pin-label">GND</text>
<text x="85" y="429" text-anchor="middle" class="pin-num">30</text>

<!-- Pin 32: GPIO12 -->
<circle cx="85" cy="460" r="6" fill="#757575" stroke="#424242" stroke-width="1.5"/> <text x="95" y="464" text-anchor="start" class="pin-label">GPIO12</text>

<text x="85" y="454" text-anchor="middle" class="pin-num">32</text>

<!-- Pin 34: GND -->
<circle cx="85" cy="485" r="6" fill="#333" stroke="#111" stroke-width="1.5"/> <text x="95" y="489" text-anchor="start" class="pin-label">GND</text>
<text x="85" y="479" text-anchor="middle" class="pin-num">34</text>

<!-- Pin 35: GPIO19 (I2S LRCLK) -->
<circle cx="55" cy="510" r="6" fill="#9C27B0" stroke="#6A1B9A" stroke-width="1.5"/> <text x="45" y="504" text-anchor="end" class="pin-num">35</text>
<text x="45" y="514" text-anchor="end" class="pin-label">GPIO19</text>

<!-- Pin 36: GPIO16 -->
<circle cx="85" cy="510" r="6" fill="#757575" stroke="#424242" stroke-width="1.5"/> <text x="95" y="514" text-anchor="start" class="pin-label">GPIO16</text>
<text x="85" y="504" text-anchor="middle" class="pin-num">36</text>

<!-- Pin 37: GPIO26 -->
<circle cx="55" cy="535" r="6" fill="#757575" stroke="#424242" stroke-width="1.5"/> <text x="45" y="529" text-anchor="end" class="pin-num">37</text>

<!-- Pin 38: GPIO20 -->
<circle cx="85" cy="535" r="6" fill="#757575" stroke="#424242" stroke-width="1.5"/> <text x="95" y="539" text-anchor="start" class="pin-label">GPIO20</text>
<text x="85" y="529" text-anchor="middle" class="pin-num">38</text>

<!-- Pin 39: GND -->
<circle cx="55" cy="555" r="6" fill="#333" stroke="#111" stroke-width="1.5"/> <text x="45" y="549" text-anchor="end" class="pin-num">39</text>

<!-- Pin 40: GPIO21 (I2S DOUT) -->
<circle cx="85" cy="555" r="6" fill="#9C27B0" stroke="#6A1B9A" stroke-width="1.5"/> <text x="95" y="559" text-anchor="start" class="pin-label">GPIO21</text>
<text x="85" y="549" text-anchor="middle" class="pin-num">40</text>

<!-- Highlight used pins with rings -->
<!-- SDA -->
<circle cx="55" cy="110" r="9" fill="none" stroke="#2196F3" stroke-width="1" stroke-dasharray="3,2"/> <!-- SCL -->
<circle cx="55" cy="135" r="9" fill="none" stroke="#2196F3" stroke-width="1" stroke-dasharray="3,2"/> <!-- GPIO4 - Button -->
<circle cx="55" cy="160" r="9" fill="none" stroke="#4CAF50" stroke-width="1" stroke-dasharray="3,2"/> <!-- GPIO17 - Encoder CLK -->
<circle cx="55" cy="210" r="9" fill="none" stroke="#4CAF50" stroke-width="1" stroke-dasharray="3,2"/> <!-- GPIO27 - Encoder DT -->
<circle cx="55" cy="235" r="9" fill="none" stroke="#4CAF50" stroke-width="1" stroke-dasharray="3,2"/> <!-- GPIO22 - Encoder SW -->

<circle cx="55" cy="260" r="9" fill="none" stroke="#4CAF50" stroke-width="1" stroke-dasharray="3,2"/> <!-- GPIO5 - Motor -->
<circle cx="55" cy="435" r="9" fill="none" stroke="#4CAF50" stroke-width="1" stroke-dasharray="3,2"/> <!-- GPIO18 - BCLK -->
<circle cx="85" cy="210" r="9" fill="none" stroke="#9C27B0" stroke-width="1" stroke-dasharray="3,2"/> <!-- GPIO19 - LRCLK -->
<circle cx="55" cy="510" r="9" fill="none" stroke="#9C27B0" stroke-width="1" stroke-dasharray="3,2"/> <!-- GPIO21 - DIN -->
<circle cx="85" cy="555" r="9" fill="none" stroke="#9C27B0" stroke-width="1" stroke-dasharray="3,2"/> </g>

<!-- ==================== COMPONENT BOXES ==================== -->

<!-- I2C BUS LABEL -->
<text x="85" y="110" text-anchor="middle" class="section-label" fill="#2196F3">I

<!-- MPU6050 -->
<g transform="translate(30, 120)">
<rect x="0" y="0" width="180" height="80" rx="6" fill="#1565C0" stroke="#0D47A1" stroke-width="1.5"/> <text x="90" y="22" text-anchor="middle" class="component-title">MPU6050 GY-521</text>
<text x="90" y="38" text-anchor="middle" class="component-detail">IMU — Posture &amp; Sleep</text> <text x="90" y="52" text-anchor="middle" class="addr-text">I²C 0x68</text>
<text x="90" y="68" text-anchor="middle" class="component-detail">VCC · GND ·
</g>

<!-- MAX30102 -->
<g transform="translate(30, 220)">
<rect x="0" y="0" width="180" height="80" rx="6" fill="#1565C0" stroke="#0D47A1" stroke-width="1.5"/> <text x="90" y="22" text-anchor="middle" class="component-title">MAX30102</text>
<text x="90" y="38" text-anchor="middle" class="component-detail">HRV — Clip inner face</text> <text x="90" y="52" text-anchor="middle" class="addr-text">I²C 0x57</text>
<text x="90" y="68" text-anchor="middle" class="component-detail">VCC · GND ·
</g>

<!-- SSD1306 OLED -->
<g transform="translate(30, 320)">
<rect x="0" y="0" width="180" height="80" rx="6" fill="#1565C0" stroke="#0D47A1" stroke-width="1.5"/> <text x="90" y="22" text-anchor="middle" class="component-title">SSD1306 / SH1106</text>
<text x="90" y="38" text-anchor="middle" class="component-detail">1.3" OLED — Back face</text> <text x="90" y="52" text-anchor="middle" class="addr-text">I²C 0x3C</text>
<text x="90" y="68" text-anchor="middle" class="component-detail">VCC · GND ·
</g>

<!-- I2C wires from components to Pi -->
<!-- MPU6050 SDA -->
<path d="M 210,155 L 320,155 Q 340,155 340,170 L 340,200 L 475,200" class="wire-i2c" marker-end="url(#arrowBlue)"/> <!-- MPU6050 SCL -->

<path d="M 210,165 L 310,165 Q 330,165 330,180 L 330,225 L 475,225" class="wire-i2c" marker-end="url(#arrowBlue)"/> <!-- MAX30102 SDA -->
<path d="M 210,255 L 300,255 Q 320,255 320,240 L 320,200 L 475,200" class="wire-i2c"/>
<!-- MAX30102 SCL -->
<path d="M 210,265 L 290,265 Q 310,265 310,250 L 310,225 L 475,225" class="wire-i2c"/> <!-- OLED SDA -->
<path d="M 210,355 L 280,355 Q 300,355 300,340 L 300,200 L 475,200" class="wire-i2c"/> <!-- OLED SCL -->
<path d="M 210,365 L 270,365 Q 290,365 290,350 L 290,225 L 475,225" class="wire-i2c"/>

<!-- I2C bus labels on wires -->
<text x="400" y="195" text-anchor="middle" font-size="9" fill="#1565C0" font-weight="bold">SDA (Pin 3)</text> <text x="400" y="220" text-anchor="middle" font-size="9" fill="#1565C0" font-weight="bold">SCL (Pin 5)</text>

<!-- 3.3V power lines to I2C devices -->
<path d="M 210,140 L 250,140 Q 260,140 260,130 L 260,95 L 380,95 L 380,175 L 475,175" class="wire-power" marker-end="url(#arrowRed)"/> <text x="350" y="88" font-size="8" fill="#F44336">3V3 (Pin 1)</text>

<!-- ==================== I2S / AUDIO (RIGHT SIDE) ==================== -->
<text x="1000" y="110" text-anchor="middle" class="section-label" fill="#9C27B0">I

<!-- MAX98357A -->
<g transform="translate(880, 120)">
<rect x="0" y="0" width="200" height="100" rx="6" fill="#6A1B9A" stroke="#4A148C" stroke-width="1.5"/> <text x="100" y="22" text-anchor="middle" class="component-title">MAX98357A</text>
<text x="100" y="38" text-anchor="middle" class="component-detail">I2S Amplifier</text>
<text x="100" y="58" text-anchor="middle" class="component-detail">VIN: 5V ·
<text x="100" y="78" text-anchor="middle" class="component-detail">GAIN: tied to GND (9dB)</text> <text x="100" y="92" text-anchor="middle" class="component-detail">SD: tied to VIN (always on)</text> </g>

<!-- Speaker -->
<g transform="translate(920, 240)">
<rect x="0" y="0" width="140" height="60" rx="6" fill="#4A148C" stroke="#311B92" stroke-width="1.5"/> <text x="70" y="22" text-anchor="middle" class="component-title">Speaker</text>
<text x="70" y="40" text-anchor="middle" class="component-detail">28–32mm · 8
<text x="70" y="54" text-anchor="middle" class="component-detail">Bare wire from amp</text>
</g>

<!-- I2S wires from Pi to MAX98357A -->
<!-- BCLK: GPIO18 (Pin 12) -->
<path d="M 505,300 L 760,300 L 760,155 L 880,155" class="wire-i2s" marker-end="url(#arrowPurple)"/>
<text x="780" y="150" font-size="9" fill="#9C27B0" font-weight="bold">BCLK</text>
<!-- LRCLK: GPIO19 (Pin 35) -->
<path d="M 475,600 L 400,600 Q 380,600 380,580 L 380,560 Q 380,540 400,540 L 750,540 Q 770,540 770,520 L 770,170 L 880,170" class="wire-i2s" marker-end="url(#arrowPurple)"/> <text x="780" y="166" font-size="9" fill="#9C27B0" font-weight="bold">LRCLK</text>
<!-- DIN: GPIO21 (Pin 40) -->

<path d="M 505,645 L 780,645 Q 800,645 800,625 L 800,190 L 880,190" class="wire-i2s" marker-end="url(#arrowPurple)"/> <text x="812" y="186" font-size="9" fill="#9C27B0" font-weight="bold">DIN</text>

<!-- 5V to amp -->
<path d="M 505,175 L 530,175 Q 550,175 550,160 L 550,140 L 880,140" class="wire-power" marker-end="url(#arrowRed)"/> <text x="700" y="135" font-size="8" fill="#D32F2F">5V (Pin 2)</text>

<!-- Speaker wire from amp -->
<path d="M 980,220 L 980,240" class="wire-i2s" stroke="#E1BEE7" marker-end="url(#arrowPurple)"/>

<!-- ==================== GPIO DEVICES (RIGHT SIDE) ==================== -->
<text x="1030" y="340" text-anchor="middle" class="section-label" fill="#4CAF50">GPIO Devices</text>

<!-- Tactile Button -->
<g transform="translate(880, 355)">
<rect x="0" y="0" width="200" height="75" rx="6" fill="#2E7D32" stroke="#1B5E20" stroke-width="1.5"/> <text x="100" y="22" text-anchor="middle" class="component-title">Tactile Button</text>
<text x="100" y="38" text-anchor="middle" class="component-detail">Top-left ·
<text x="100" y="55" text-anchor="middle" class="component-detail">GPIO4 (Pin 7)
<text x="100" y="68" text-anchor="middle" class="component-detail">Internal pull-up </g>

<!-- Button wire -->
<path d="M 475,250 L 420,250 Q 400,250 400,270 L 400,390 L 880,390" class="wire-gpio" marker-end="url(#arrowGreen)"/> <text x="640" y="384" font-size="9" fill="#4CAF50" font-weight="bold">GPIO4 (Pin 7)</text>

<!-- EC11 Rotary Encoder -->
<g transform="translate(880, 450)">
<rect x="0" y="0" width="200" height="95" rx="6" fill="#2E7D32" stroke="#1B5E20" stroke-width="1.5"/> <text x="100" y="22" text-anchor="middle" class="component-title">EC11 Encoder</text>
<text x="100" y="38" text-anchor="middle" class="component-detail">Top-right
<text x="100" y="55" text-anchor="middle" class="component-detail">CLK → GPIO17 (Pin 11)</text> <text x="100" y="68" text-anchor="middle" class="component-detail">DT → GPIO27 (Pin 13)</text> <text x="100" y="81" text-anchor="middle" class="component-detail">SW → GPIO22 (Pin 15)</text> </g>

<!-- Encoder wires -->
<!-- CLK: GPIO17 -->
<path d="M 475,300 L 430,300 Q 410,300 410,320 L 410,475 L 880,475" class="wire-gpio" marker-end="url(#arrowGreen)"/> <!-- DT: GPIO27 -->
<path d="M 475,325 L 440,325 Q 420,325 420,345 L 420,490 L 880,490" class="wire-gpio" marker-end="url(#arrowGreen)"/> <!-- SW: GPIO22 -->
<path d="M 475,350 L 450,350 Q 430,350 430,370 L 430,505 L 880,505" class="wire-gpio" marker-end="url(#arrowGreen)"/>

<!-- 10nF debounce note -->
<g transform="translate(880, 550)">
<rect x="0" y="0" width="200" height="32" rx="4" fill="#E8F5E9" stroke="#A5D6A7" stroke-width="1"/>

<text x="100" y="20" text-anchor="middle" class="note-text" fill="#2E7D32">10nF caps on CLK &amp; DT to GND</text> </g>

<!-- ==================== VIBRATION MOTOR (BOTTOM LEFT) ==================== -->
<g transform="translate(30, 470)">
<rect x="0" y="0" width="200" height="120" rx="6" fill="#E65100" stroke="#BF360C" stroke-width="1.5"/> <text x="100" y="22" text-anchor="middle" class="component-title">Coin Vibration Motor</text>
<text x="100" y="40" text-anchor="middle" class="component-detail">Haptic nudges
<text x="100" y="60" text-anchor="middle" class="component-detail" fill="#FFE0B2">GPIO5 (Pin 29)
<text x="100" y="76" text-anchor="middle" class="component-detail" fill="#FFE0B2">2N2222 NPN transistor</text> <text x="100" y="92" text-anchor="middle" class="component-detail" fill="#FFE0B2">1N4001 flyback diode</text> <text x="100" y="108" text-anchor="middle" class="component-detail" fill="#FFE0B2">Motor+
</g>

<!-- Motor wire: GPIO5 (Pin 29) -->
<path d="M 475,525 L 350,525 Q 330,525 330,530 L 330,530 L 230,530" class="wire-gpio" marker-end="url(#arrowGreen)"/> <text x="340" y="520" font-size="9" fill="#4CAF50" font-weight="bold">GPIO5 (Pin 29)</text>

<!-- ==================== USB CAMERA (BOTTOM) ==================== -->
<g transform="translate(30, 620)">
<rect x="0" y="0" width="200" height="80" rx="6" fill="#E65100" stroke="#BF360C" stroke-width="1.5"/>
<text x="100" y="22" text-anchor="middle" class="component-title">OV9712 Camera</text>
<text x="100" y="38" text-anchor="middle" class="component-detail">720p USB UVC
<text x="100" y="56" text-anchor="middle" class="component-detail" fill="#FFE0B2">USB OTG port (micro-USB)</text>
<text x="100" y="72" text-anchor="middle" class="component-detail" fill="#FFE0B2">Flat ribbon cable internal route</text> </g>

<!-- USB wire to Pi OTG -->
<path d="M 230,660 L 360,660 Q 380,660 380,680 L 380,700 Q 380,710 400,710 L 525,710 Q 545,710 545,695 L 545,650" class="wire-usb" marker-end="url(#arrowOrange)"/> <text x="480" y="705" font-size="9" fill="#FF9800" font-weight="bold">USB OTG</text>

<!-- ==================== POWER (BOTTOM RIGHT) ==================== -->
<g transform="translate(880, 620)">
<rect x="0" y="0" width="200" height="80" rx="6" fill="#B71C1C" stroke="#880E0E" stroke-width="1.5"/> <text x="100" y="22" text-anchor="middle" class="component-title">Power Bank</text>
<text x="100" y="38" text-anchor="middle" class="component-detail">10,000 mAh
<text x="100" y="56" text-anchor="middle" class="component-detail" fill="#FFCDD2">USB-C cable
<text x="100" y="72" text-anchor="middle" class="component-detail" fill="#FFCDD2">
</g>

<!-- Power wire -->
<path d="M 880,660 L 620,660 Q 600,660 600,650 L 600,640" class="wire-power" marker-end="url(#arrowRed)"/> <text x="740" y="654" font-size="9" fill="#D32F2F" font-weight="bold">USB-C + XT30</text>

<!-- ==================== LEGEND ==================== -->
<g transform="translate(30, 760)">
<rect x="0" y="0" width="1340" height="70" rx="6" fill="#fff" stroke="#ddd" stroke-width="1"/>

<text x="20" y="20" font-size="12" font-weight="bold" fill="#333">Legend</text>

<line x1="20" y1="40" x2="60" y2="40" class="wire-i2c"/>
<text x="68" y="44" class="legend-text">I²C (SDA/SCL shared bus)</text>

<line x1="240" y1="40" x2="280" y2="40" class="wire-i2s"/>
<text x="288" y="44" class="legend-text">I²S (BCLK/LRCLK/DIN)</text>

<line x1="470" y1="40" x2="510" y2="40" class="wire-gpio"/>
<text x="518" y="44" class="legend-text">GPIO (digital I/O)</text>

<line x1="650" y1="40" x2="690" y2="40" class="wire-power"/> <text x="698" y="44" class="legend-text">Power (3V3 / 5V)</text>

<line x1="820" y1="40" x2="860" y2="40" class="wire-gnd"/> <text x="868" y="44" class="legend-text">Ground</text>

<line x1="960" y1="40" x2="1000" y2="40" class="wire-usb"/> <text x="1008" y="44" class="legend-text">USB</text>

<circle cx="1120" cy="40" r="5" fill="#757575"/>
<text x="1132" y="44" class="legend-text">Unused pin</text>
</g>

<!-- ==================== PIN ASSIGNMENT TABLE ==================== -->
<g transform="translate(30, 850)">
<rect x="0" y="0" width="1340" height="180" rx="6" fill="#fff" stroke="#ddd" stroke-width="1"/>
<text x="20" y="24" font-size="13" font-weight="bold" fill="#333">Complete Pin Assignment Table</text>

<!-- Header -->
<text x="20" y="50" font-size="10" font-weight="bold" fill="#555">Pin</text>
<text x="70" y="50" font-size="10" font-weight="bold" fill="#555">GPIO</text> <text x="140" y="50" font-size="10" font-weight="bold" fill="#555">Function</text> <text x="320" y="50" font-size="10" font-weight="bold" fill="#555">Component</text>

<text x="500" y="50" font-size="10" font-weight="bold" fill="#555">Pin</text> <text x="550" y="50" font-size="10" font-weight="bold" fill="#555">GPIO</text> <text x="620" y="50" font-size="10" font-weight="bold" fill="#555">Function</text> <text x="800" y="50" font-size="10" font-weight="bold" fill="#555">Component</text>

<line x1="20" y1="56" x2="470" y2="56" stroke="#eee" stroke-width="1"/>
<line x1="500" y1="56" x2="970" y2="56" stroke="#eee" stroke-width="1"/>

<!-- Left column data -->
<text x="20" y="72" font-size="10" fill="#F44336" font-weight="bold">1</text> <text x="70" y="72" font-size="10" fill="#333">—</text>
<text x="140" y="72" font-size="10" fill="#333">3.3V Power</text>

<text x="320" y="72" font-size="10" fill="#333">MPU6050, MAX30102, OLED, Motor</text>

<text x="20" y="88" font-size="10" fill="#2196F3" font-weight="bold">3</text>
<text x="70" y="88" font-size="10" fill="#333">GPIO2</text>
<text x="140" y="88" font-size="10" fill="#333">I²C SDA</text>
<text x="320" y="88" font-size="10" fill="#333">MPU6050 + MAX30102 + OLED</text>

<text x="20" y="104" font-size="10" fill="#2196F3" font-weight="bold">5</text> <text x="70" y="104" font-size="10" fill="#333">GPIO3</text>
<text x="140" y="104" font-size="10" fill="#333">I²C SCL</text>
<text x="320" y="104" font-size="10" fill="#333">MPU6050 + MAX30102 + OLED</text>

<text x="20" y="120" font-size="10" fill="#4CAF50" font-weight="bold">7</text> <text x="70" y="120" font-size="10" fill="#333">GPIO4</text>
<text x="140" y="120" font-size="10" fill="#333">Button (interrupt)</text> <text x="320" y="120" font-size="10" fill="#333">Tactile button → GND</text>

<text x="20" y="136" font-size="10" fill="#4CAF50" font-weight="bold">11</text> <text x="70" y="136" font-size="10" fill="#333">GPIO17</text>
<text x="140" y="136" font-size="10" fill="#333">Encoder CLK</text>
<text x="320" y="136" font-size="10" fill="#333">EC11 + 10nF to GND</text>

<text x="20" y="152" font-size="10" fill="#4CAF50" font-weight="bold">13</text> <text x="70" y="152" font-size="10" fill="#333">GPIO27</text>
<text x="140" y="152" font-size="10" fill="#333">Encoder DT</text>
<text x="320" y="152" font-size="10" fill="#333">EC11 + 10nF to GND</text>

<text x="20" y="168" font-size="10" fill="#4CAF50" font-weight="bold">15</text> <text x="70" y="168" font-size="10" fill="#333">GPIO22</text>
<text x="140" y="168" font-size="10" fill="#333">Encoder SW (click)</text> <text x="320" y="168" font-size="10" fill="#333">EC11 push-button</text>

<!-- Right column data -->
<text x="500" y="72" font-size="10" fill="#D32F2F" font-weight="bold">2</text> <text x="550" y="72" font-size="10" fill="#333">—</text>
<text x="620" y="72" font-size="10" fill="#333">5V Power</text>
<text x="800" y="72" font-size="10" fill="#333">MAX98357A (VIN)</text>

<text x="500" y="88" font-size="10" fill="#9C27B0" font-weight="bold">12</text> <text x="550" y="88" font-size="10" fill="#333">GPIO18</text>
<text x="620" y="88" font-size="10" fill="#333">I²S BCLK</text>
<text x="800" y="88" font-size="10" fill="#333">MAX98357A</text>

<text x="500" y="104" font-size="10" fill="#9C27B0" font-weight="bold">35</text> <text x="550" y="104" font-size="10" fill="#333">GPIO19</text>
<text x="620" y="104" font-size="10" fill="#333">I²S LRCLK</text>
<text x="800" y="104" font-size="10" fill="#333">MAX98357A</text>

<text x="500" y="120" font-size="10" fill="#9C27B0" font-weight="bold">40</text> <text x="550" y="120" font-size="10" fill="#333">GPIO21</text>
<text x="620" y="120" font-size="10" fill="#333">I²S DIN</text>
<text x="800" y="120" font-size="10" fill="#333">MAX98357A</text>

<text x="500" y="136" font-size="10" fill="#4CAF50" font-weight="bold">29</text> <text x="550" y="136" font-size="10" fill="#333">GPIO5</text>
<text x="620" y="136" font-size="10" fill="#333">Motor drive</text>
<text x="800" y="136" font-size="10" fill="#333">→ 1kΩ → 2N2222 base</text>

<text x="500" y="152" font-size="10" fill="#333" font-weight="bold">6,9,14...</text> <text x="550" y="152" font-size="10" fill="#333">—</text>
<text x="620" y="152" font-size="10" fill="#333">GND</text>
<text x="800" y="152" font-size="10" fill="#333">All components share ground</text>

<text x="500" y="168" font-size="10" fill="#FF9800" font-weight="bold">USB</text> <text x="550" y="168" font-size="10" fill="#333">OTG</text>
<text x="620" y="168" font-size="10" fill="#333">USB device port</text>
<text x="800" y="168" font-size="10" fill="#333">OV9712 camera (flat ribbon)</text>

<!-- Unused pins note -->
<text x="1050" y="72" font-size="10" fill="#999" font-style="italic">Unused GPIO: 0, 1, 5–16</text>
<text x="1050" y="88" font-size="10" fill="#999" font-style="italic">(SPI, UART, extras)</text>
<text x="1050" y="104" font-size="10" fill="#999" font-style="italic">Available for future sensors</text> <text x="1050" y="130" font-size="10" fill="#999" font-style="italic">Total pins used: 10 of 26 GPIO</text> <text x="1050" y="146" font-size="10" fill="#999" font-style="italic">+ 2 power + USB OTG</text>
</g>
</svg>

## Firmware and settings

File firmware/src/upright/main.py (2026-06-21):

"""Main entrypoint — wires HAL → event bus → ModeManager → services.

On the Pi this is started as ``python -m upright.main`` by
``systemd/upright.service``. Pass ``--dry-run`` to start the loop with all
HAL drivers in stub mode (no GPIO / I²C touched). Useful on macOS.
"""

from __future__ import annotations

import argparse
import logging
import signal
import sys
import threading
import time
from pathlib import Path

from . import __version__
from .config import reload_tunables
from .events import Event, EventBus, EventType
from .hal.display import Display
from .modes.manager import ModeManager
from .services import alerts as alerts_service
from .services import boot as boot_service
from .services import demo_seed
from .services import logger as logger_service
from .services import meds as meds_service
from .services import sleep as sleep_service

log = logging.getLogger("upright")

# Boot OLED animation only after Pi power-on, not on `systemctl restart upright`.
_COLD_BOOT_MAX_UPTIME_S = 120.0


def _kernel_uptime_s() -> float:
    try:
        return float(Path("/proc/uptime").read_text().split()[0])
    except (OSError, ValueError, IndexError):
        return 9999.0


def is_cold_boot() -> bool:
    return _kernel_uptime_s() < _COLD_BOOT_MAX_UPTIME_S


def _setup_logging() -> None:
    logging.basicConfig(
        level=logging.INFO,
        format="%(asctime)s %(levelname)-7s %(name)s: %(message)s",
        datefmt="%H:%M:%S",
    )


def _init_gpio_pins(*, dry_run: bool) -> None:
    """Claim GPIO via lgpio before luma opens SPI (avoids SPI deadlocks on Pi)."""
    if dry_run:
        return
    from .config import PIN_BUTTON_A, PIN_BUTTON_B, PIN_LIPO_ALERT, PIN_MOTOR
    from .hal.gpio_lgpio import claim_input, claim_output

    claim_output(PIN_MOTOR, initial=0)
    claim_input(PIN_BUTTON_A)
    claim_input(PIN_BUTTON_B)
    claim_input(PIN_LIPO_ALERT)


def _start_hal(bus: EventBus, dry_run: bool) -> list[threading.Thread]:
    """Start every HAL polling thread. Returns the list so they can be joined."""
    from .hal import button, imu, power
    from .services import provisioning, timesync

    threads: list[threading.Thread] = []
    threads.append(imu.start_thread(bus, dry_run=dry_run))
    threads.append(power.start_thread(bus, dry_run=dry_run))
    threads.append(button.start_thread(bus, dry_run=dry_run))
    # Bring up the setup AP when there's no Wi-Fi so first-time provisioning works.
    threads.append(provisioning.start_thread(dry_run=dry_run))
    # Keep the (RTC-less) clock correct: chrony nudge + HTTP-Date fallback.
    threads.append(timesync.start_thread(dry_run=dry_run))
    return threads


def _run_boot_sequence(
    manager: ModeManager,
    bus: EventBus,
    db: logger_service.Logger,
    *,
    dry_run: bool,
    demo_mode: bool,
) -> None:
    """Drive the OLED boot screen from real init steps."""
    manager.begin_boot()

    manager.set_boot_status("Display", "Panel init", progress=0.08)
    time.sleep(0.05)

    manager.set_boot_status("Database", "Opening store", progress=0.22)
    if demo_mode:
        demo_seed.restart_demo_on_boot(db)
        manager.meds._refresh_schedule()
    db.boot_session()
    time.sleep(0.05)

    manager.set_boot_status("Services", "Alerts & sleep", progress=0.38)

    found, i2c_line = boot_service.scan_summary(dry_run=dry_run)
    manager.set_boot_status("I2C bus", i2c_line, progress=0.52, devices=i2c_line)
    if not dry_run and found:
        from .hal.i2c_probe import log_scan_results

        log_scan_results(found)

    manager.set_boot_status("Sensors", "Starting threads", progress=0.65)
    hal_threads = _start_hal(bus, dry_run=dry_run)

    manager.set_boot_status("Sensors", "First readings", progress=0.78)
    imu_ok, power_ok = boot_service.wait_for_hal_samples(bus, timeout_s=3.5)
    status = boot_service.sensor_status_line(
        imu_ok=imu_ok, power_ok=power_ok, dry_run=dry_run
    )
    manager.set_boot_status(
        "Sensors",
        status,
        progress=0.92,
        devices=status,
    )
    time.sleep(0.08)

    manager.finish_boot()
    return hal_threads


def _warm_startup(
    manager: ModeManager,
    bus: EventBus,
    db: logger_service.Logger,
    *,
    dry_run: bool,
    demo_mode: bool,
) -> list[threading.Thread]:
    """Service restart — no boot screen; go straight to watch face."""
    from .modes.states import State

    log.info(
        "warm start (kernel uptime %.0fs) — skipping boot screen",
        _kernel_uptime_s(),
    )
    if demo_mode and is_cold_boot():
        demo_seed.restart_demo_on_boot(db)
        manager.meds._refresh_schedule()
    db.boot_session()
    manager._boot_complete = True
    manager.ctx.state = State.IDLE
    try:
        from .modes import ui

        ui.render(State.IDLE, manager._view_ctx(), manager.oled)
        manager._last_render = time.time()
    except Exception as e:
        log.warning("initial watch render failed: %s", e)
    return _start_hal(bus, dry_run=dry_run)


def main(argv: list[str] | None = None) -> int:
    parser = argparse.ArgumentParser(prog="upright", description="UpRight firmware")
    parser.add_argument("--dry-run", action="store_true", help="run with HAL stubs (no GPIO/I²C)")
    parser.add_argument("--version", action="store_true")
    args = parser.parse_args(argv)

    if args.version:
        print(f"upright {__version__}")
        return 0

    _setup_logging()
    tunables = reload_tunables()
    log.info("UpRight v%s starting (dry_run=%s)", __version__, args.dry_run)
    log.info("Wear side: %s | language: %s", tunables.wear_side, tunables.language)

    bus = EventBus()
    db = logger_service.Logger()

    alerts = alerts_service.AlertManager(bus)
    sleep = sleep_service.SleepTracker(bus)
    meds = meds_service.MedReminders(bus, db)

    _init_gpio_pins(dry_run=args.dry_run)

    oled = Display(dry_run=args.dry_run, autoprobe=not args.dry_run)

    if not args.dry_run:
        from .hal.gpio_lgpio import reclaim_button_inputs

        reclaim_button_inputs()

    manager = ModeManager(
        bus, db, alerts=alerts, sleep=sleep, meds=meds, display=oled
    )

    if is_cold_boot():
        log.info("cold boot detected — showing startup screen")
        hal_threads = _run_boot_sequence(
            manager,
            bus,
            db,
            dry_run=args.dry_run,
            demo_mode=bool(tunables.demo_mode),
        )
    else:
        hal_threads = _warm_startup(
            manager,
            bus,
            db,
            dry_run=args.dry_run,
            demo_mode=bool(tunables.demo_mode),
        )

    stop_evt = threading.Event()

    def _shutdown(signum, _frame):
        log.info("signal %s received — shutting down", signum)
        stop_evt.set()
        bus.publish(Event(EventType.SHUTDOWN))

    signal.signal(signal.SIGTERM, _shutdown)
    signal.signal(signal.SIGINT, _shutdown)

    try:
        manager.run(stop_evt)
    finally:
        log.info("flushing database…")
        db.flush()
        db.close()
        for t in hal_threads:
            t.join(timeout=1.0)
        log.info("bye")
    return 0


if __name__ == "__main__":  # pragma: no cover
    sys.exit(main())

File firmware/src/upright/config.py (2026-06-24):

"""Central configuration: pins, addresses, thresholds, file paths.

Values can be overridden at runtime by ``data/config.json`` (hot-reloaded by
``services.boot`` / the web settings page when running on the Pi).
"""

from __future__ import annotations

import json
from dataclasses import asdict, dataclass, fields
from pathlib import Path

PKG_ROOT = Path(__file__).resolve().parent
FIRMWARE_ROOT = PKG_ROOT.parent.parent  # firmware/
DATA_DIR = FIRMWARE_ROOT / "data"
AUDIO_DIR = FIRMWARE_ROOT / "audio"
MODELS_DIR = FIRMWARE_ROOT / "models"

DB_PATH = DATA_DIR / "upright.db"
CONFIG_PATH = DATA_DIR / "config.json"
FOODS_PATH = DATA_DIR / "foods.json"
TFLITE_MODEL_PATH = MODELS_DIR / "food_mobilenetv2_quant.tflite"


# --- Pins (BCM numbering) ---------------------------------------------------

PIN_BUTTON_A = 20  # physical header pin 38
PIN_BUTTON_B = 21  # physical header pin 40 — also Pi I2S DIN; see docs
PIN_LIPO_ALERT = 4  # Pimoroni Zero LiPo low-battery alert (active low)
PIN_MOTOR = 22  # physical header pin 15 (motor IN)
PIN_ENCODER_CLK = 17
PIN_ENCODER_DT = 27  # also MPU6050 SDA (bit-bang I²C) — encoder not fitted
PIN_ENCODER_SW = 22  # unused — encoder not fitted; shares BCM 22 with motor
# MPU6050 bit-bang I²C. SCL must NOT be GPIO 28 on Pi Zero 2 W (SDIO — "GPIO busy").
PIN_MPU6050_SDA = 27
PIN_MPU6050_SCL = 3  # header pin 5; was 28 in early docs (invalid on Zero 2 W)
PIN_MPU6050_INT = 13  # optional data-ready; polling used for now
# Legacy header I²C (unused on this build — sensors on GPIO 27/28).
PIN_I2C_SDA = 2
PIN_I2C_SCL = 3
PIN_I2S_BCLK = 18
PIN_I2S_LRC = 19
PIN_I2S_DIN = 21

# Prefer firmware bit-bang on GPIO 27/28 (see hal/i2c_bitbang.py). Kernel overlay optional.
MPU_I2C_GPIO_OVERLAY = "i2c-gpio,i2c_gpio_sda=27,i2c_gpio_scl=3,i2c_gpio_delay_us=5"
USE_KERNEL_MPU_I2C = False
# MOSI=10, SCLK=11, CE0=8 — CS handled by spidev; DC/RST below.

SPI_DISPLAY_PORT = 0
SPI_DISPLAY_DEVICE = 0
SPI_DISPLAY_DC = 25
SPI_DISPLAY_RST = 24
SPI_DISPLAY_BL = -1  # leave to display driver; set a GPIO number only if needed
SPI_DISPLAY_WIDTH = 128
SPI_DISPLAY_HEIGHT = 128
SPI_DISPLAY_H_OFFSET = 0
SPI_DISPLAY_V_OFFSET = 0


# --- I2C addresses ---------------------------------------------------------

I2C_ADDR_MPU6050 = 0x68
I2C_ADDR_OLED = 0x3C  # SH1106 modules sometimes use 0x3D


# --- OLED ------------------------------------------------------------------

OLED_WIDTH = 128
OLED_HEIGHT = 64
# Legacy constant; display blanking uses Tunables.display_blank_minutes at runtime.
OLED_AUTO_BLANK_SECONDS = 0

# SPI TFT: minimum seconds between full-frame paints (reduces visible scan “wave”).
DISPLAY_MIN_REFRESH_SECONDS = 2.0
# Watch-face pitch/posture line can refresh more often.
DISPLAY_PITCH_REFRESH_SECONDS = 1.0


# --- Tunables (overridable via config.json) --------------------------------


@dataclass
class Tunables:
    # Posture — tuned for GERD (see reference docs/posture-detection.md)
    # Daytime: trunk slouch ~12°+; post-meal: stricter ~8°; lying flat ~55°+ is worst.
    pitch_alert_deg: float = 12.0
    pitch_alert_strict_deg: float = 8.0  # POST_MEAL slouch
    pitch_sustained_seconds: float = 45.0
    lying_flat_deg: float = 55.0  # torso near horizontal (post-meal reflux risk)
    lying_sustained_seconds: float = 20.0  # after lying_grace_seconds
    posture_sample_hz_idle: float = 2.0
    posture_sample_hz_post_meal: float = 5.0
    posture_sample_hz_sleep: float = 0.03  # one sample every ~33s

    # Posture score mapping (display + slouch logic)
    posture_deadzone_deg: float = 5.0
    posture_pct_slope: float = 1.5  # gentler fall-off than legacy 3.0
    imu_smooth_alpha: float = 0.18  # EMA weight for new accel samples (lower = smoother)
    pitch_display_alpha: float = 0.25  # extra UI smoothing in the mode manager

    # Alerts
    alert_cooldown_seconds: float = 300.0
    lying_grace_seconds: float = 120.0
    voice_alerts_enabled: bool = True
    haptic_alerts_enabled: bool = True

    # Meal window
    post_meal_default_hours: float = 2.5

    # Sleep
    sleep_window_start: str = "23:00"
    sleep_window_end: str = "07:00"
    sleep_pre_stillness_minutes: float = 10.0
    sleep_wake_movement_minutes: float = 2.0
    sleep_stillness_pitch_deg: float = 3.0
    sleep_stillness_roll_std_deg: float = 2.0
    sleep_window_required: bool = False
    sleep_lying_flat_shortcut_minutes: float = 5.0
    sleep_max_nudges: int = 3
    sleep_nudge_gap_seconds: float = 300.0
    wear_side: str = "left"  # left | right | center

    # Camera / TFLite. The bundled AIY Food V1 model has 2024 fine-grained
    # classes, so a correct top-1 for a real plate is typically 0.3–0.85 while
    # Non-food / empty frames normalize below ~0.08; real dishes land around
    # 0.12–0.25 after the model's sparse score mass is renormalized.
    food_min_confidence: float = 0.12
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

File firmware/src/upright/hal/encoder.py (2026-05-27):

"""EC11 rotary encoder via lgpio (same stack as buttons; avoids RPi.GPIO vs SPI)."""

from __future__ import annotations

import logging
import threading
import time

from ..config import PIN_ENCODER_CLK, PIN_ENCODER_DT, PIN_ENCODER_SW
from ..events import Event, EventBus, EventType
from .gpio_lgpio import claim_input, read_gpio

log = logging.getLogger("hal.encoder")

_ROTATE_DEBOUNCE_S = 0.04


def _loop(evt_bus: EventBus, stop: threading.Event) -> None:  # pragma: no cover
    for pin in (PIN_ENCODER_CLK, PIN_ENCODER_DT, PIN_ENCODER_SW):
        claim_input(pin)

    last_clk = read_gpio(PIN_ENCODER_CLK)
    last_sw = read_gpio(PIN_ENCODER_SW)
    last_rotate = 0.0

    log.info(
        "encoder on GPIO CLK=%s DT=%s SW=%s",
        PIN_ENCODER_CLK,
        PIN_ENCODER_DT,
        PIN_ENCODER_SW,
    )

    while not stop.is_set():
        clk = read_gpio(PIN_ENCODER_CLK)
        dt = read_gpio(PIN_ENCODER_DT)
        if clk != last_clk:
            now = time.time()
            if now - last_rotate >= _ROTATE_DEBOUNCE_S:
                direction = "cw" if dt != clk else "ccw"
                evt_bus.publish(Event(EventType.ENCODER_ROTATE, payload={"dir": direction}))
                last_rotate = now
            last_clk = clk

        sw = read_gpio(PIN_ENCODER_SW)
        if last_sw == 1 and sw == 0:
            evt_bus.publish(Event(EventType.ENCODER_CLICK))
        last_sw = sw
        time.sleep(0.002)


def _stub_loop(evt_bus: EventBus, stop: threading.Event) -> None:
    while not stop.is_set():
        stop.wait(60.0)


def start_thread(evt_bus: EventBus, *, dry_run: bool) -> threading.Thread:
    stop = threading.Event()
    if dry_run:
        target = lambda: _stub_loop(evt_bus, stop)  # noqa: E731
    else:
        try:
            for pin in (PIN_ENCODER_CLK, PIN_ENCODER_DT, PIN_ENCODER_SW):
                claim_input(pin)
            target = lambda: _loop(evt_bus, stop)  # noqa: E731
        except Exception as e:
            log.error("encoder init failed (%s)", e)
            target = lambda: _stub_loop(evt_bus, stop)  # noqa: E731
    th = threading.Thread(target=target, name="hal.encoder", daemon=True)
    th.stop = stop  # type: ignore[attr-defined]
    th.start()
    log.info("encoder thread started (dry_run=%s)", dry_run)
    return th

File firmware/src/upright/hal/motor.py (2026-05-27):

"""Coin vibration motor on GPIO 22 / physical pin 15 (via driver transistor)."""

from __future__ import annotations

import logging
import threading
import time

from ..config import PIN_MOTOR
from .gpio_lgpio import claim_output, write

log = logging.getLogger("hal.motor")

# GPIO is on/off only — longer bursts + more repeats = stronger perceived haptic.
PATTERNS: dict[str, list[float]] = {
    "gentle": [0.30, 0.12, 0.30, 0.0],
    "moderate": [0.45, 0.15, 0.45, 0.15, 0.45, 0.0],
    "strong": [0.65, 0.18, 0.65, 0.18, 0.65, 0.18, 0.65, 0.0],
    "max": [
        0.95,
        0.18,
        0.95,
        0.18,
        0.95,
        0.18,
        0.95,
        0.18,
        0.95,
        0.0,
    ],
}


class Motor:
    def __init__(self, *, dry_run: bool = False) -> None:
        self._dry_run = dry_run
        self._ready = False
        if not dry_run:
            try:
                claim_output(PIN_MOTOR, initial=0)
                self._ready = True
            except Exception as e:
                log.error("motor init failed (%s) — running in stub mode", e)

    def buzz(self, pattern: str = "gentle") -> None:
        seq = PATTERNS.get(pattern, PATTERNS["gentle"])
        log.info("buzz: %s", pattern)
        if not self._ready:
            return
        for i, dur in enumerate(seq):
            write(PIN_MOTOR, 1 if i % 2 == 0 else 0)
            time.sleep(dur)
        write(PIN_MOTOR, 0)

    def buzz_async(self, pattern: str = "gentle") -> None:
        threading.Thread(target=self.buzz, args=(pattern,), daemon=True).start()

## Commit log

2026-04-09 Initial commit: Reflux Sentinel firmware + PWA
    Offline GERD wearable for Raspberry Pi Zero 2 W.
    - Event-driven FSM with 8 states (IDLE, POST_MEAL, FOOD_PHOTO,
    PRE_SLEEP, SLEEPING, CALIBRATING, ONBOARDING, BOOTING)
    - HAL drivers for MPU6050 IMU, MAX30102 HRV, SH1106 OLED, OV9712
    camera, MAX98357A I2S amp, tactile button, EC11 encoder, vibration
    motor — all lazy-imported so the package loads on macOS for tests
    - SQLite logger with WAL + batched writes, inbox table for webapp IPC
    - Alerts service with cooldowns, escalation ladder, lying-down grace
    - Sleep tracker with wear-side aware position classification + nudge
    ladder (max 3/night)
    - Food risk dict (~180 entries) + optional TFLit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
    [audio.py, button.py, button_test.py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]
2026-05-27 Refactor project from Reflux Sentinel to UpRight
    - Updated project name and references from "Reflux Sentinel" to "UpRight" across all files.
    - Changed database files in .gitignore to reflect new naming convention.
    - Modified install.sh to install and configure UpRight services and systemd units.
    - Updated README and documentation to align with the new project name and functionality.
    - Removed obsolete CAD directory and related files.
    - Refactored firmware structure, including renaming modules and scripts to use the UpRight namespace.
    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
    [camera mount.stl, center piece.stl, cover.stl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]
2026-05-27 Update documentation and firmware configuration
    - Added a reference to the new PI_REMOTE_RUNBOOK.md for remote SSH/service troubleshooting in DEV.md.
    - Reduced SPI bus speed from 2MHz to 1MHz in display configuration files for improved stability.
    - Introduced a new SPI_DISPLAY_BL configuration in config.py to manage backlight control.
    - Implemented a method to force the display backlight on in display.py, enhancing display visibility.
    - Updated pi-enable-hardware.sh to disable I2S and HifiBerry overlays to prevent GPIO conflicts with buttons.
    [config.py, display.py]
2026-05-27 Improve TFT readability and update efficiency.
    Raise display loop cadence while skipping unchanged frames, and switch the TFT UI palette to high-contrast black-on-white for clearer text on the ST7735 panel.
    [display.py, manager.py, ui.py]
2026-05-27 Update display configuration and dependencies
    - Added adafruit-blinka and adafruit-circuitpython-rgb-display dependencies for enhanced hardware support.
    - Reduced SPI bus speed from 1MHz to 500kHz in display configuration for improved stability.
    - Updated display handling to support RGB swapping and resizing based on configuration settings.
    [display.py, pi_display_calibrate.py, pi_display_recover.py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]
2026-05-27 Update display configuration and UI rendering
    - Changed display driver to adafruit_st7735r and adjusted display dimensions to 128x160.
    - Updated GPIO pin assignments for DC and RST in configuration files.
    - Enhanced UI rendering by modifying posture percentage calculation and pitch rounding for improved accuracy.
    - Adjusted rendering frequency to reduce load on the display loop.
2026-05-27 Refactor display handling and improve UI responsiveness
    - Updated display configuration to support new dimensions and panel orientation for the ST7735 display.
    - Enhanced UI rendering logic to minimize unnecessary updates, improving performance and reducing flicker.
    - Adjusted button mapping for better user interaction and refined encoder handling for smoother input.
    - Implemented GPIO handling via lgpio for improved reliability and performance in hardware interactions.
    - Removed obsolete documentation files to streamline project structure.
2026-05-27 Enhance menu navigation and symptom logging functionality
    - Updated the menu system to utilize a two-button interface, replacing the encoder controls.
    - Introduced new symptom severity and type selection features, allowing users to log symptoms more effectively.
    - Improved the UI layout and interaction flow, including menu transitions and action confirmations.
    - Revised documentation to reflect changes in button mapping and menu structure.
2026-05-27 Refactor button classification and UI interaction logic
    - Adjusted button hold thresholds for improved responsiveness: Button A now requires a longer hold (2.2s) to trigger a long press, while Button B requires 1.8s.
    - Introduced a new `classify_hold` function to streamline hold duration classification.
    - Updated button state mapping to reflect new thresholds and removed obsolete mapping logic.
    - Enhanced logging to provide clearer information on button press durations.
    - Revised UI text hints to better guide user interactions with buttons.
2026-05-27 Refactor button handling and UI feedback
    - Standardized button hold thresholds for both buttons to 1.8s for long presses, improving consistency in user interactions.
    - Simplified button state management by removing individual long threshold parameters and introducing a cooldown mechanism.
    - Enhanced battery icon rendering in the UI for better visual clarity and updated text hints for button actions.
    - Adjusted test cases to reflect new hold duration logic for button classification.
    - Updated documentation to align with the revised button mapping and interaction model.
2026-05-27 Enhance posture tracking and UI responsiveness
    - Introduced new tunables for posture scoring and display smoothing, allowing for more frequent updates and refined calculations.
    - Updated IMU handling to improve posture data accuracy with exponential moving averages for pitch and roll.
    - Enhanced the ModeManager to better manage posture display and menu interactions, including new food preview functionality.
    - Improved UI text for clarity and adjusted button hints in the documentation to reflect recent changes in button actions.
    - Refined the rendering logic for food photo capture and analysis, ensuring smoother transitions and better user feedback.
2026-05-27 Refactor I²C scanning and battery monitoring functionality
    - Updated the I²C scan script to require sudo for proper bus access and improved device detection logic.
    - Enhanced motor test script to include a new "max" buzz pattern and adjusted timing for better user experience.
    - Refined battery monitoring in the power module to support I²C fuel gauge and INA219, with fallback to alert pin.
    - Improved UI battery icon rendering to indicate charging status and low battery warnings more clearly.
    - Updated ModeManager to handle new battery state information, including source tracking and low battery alerts.
    [config.py, i2c_probe.py, i2c_scan.py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]
2026-05-27 Update button handling, motor configuration, and sleep tracking features
    - Adjusted button classification logic to allow per-button timing, enhancing responsiveness for Button A and Button B.
    - Updated motor configuration to reflect new GPIO pin assignments for improved clarity in wiring documentation.
    - Enhanced sleep tracking functionality to provide detailed sleep reports and context for UI rendering, including sleep scores and nudge information.
    - Improved UI elements to display sleep state and related metrics more effectively, ensuring better user feedback during sleep mode.
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2026-05-27 Refactor button handling and update MPU6050 integration
    - Simplified button classification logic to focus on single, double, and triple taps, removing long press detection.
    - Updated button test script to reflect changes in classification and removed obsolete hold duration tests.
    - Adjusted MPU6050 wiring documentation and configuration to ensure correct GPIO pin assignments for bit-banging.
    - Enhanced UI feedback for button actions, including updated hints and documentation for user interactions.
    - Improved I²C handling to prevent ghost bus issues and ensure reliable communication with the MPU6050.
    [button.py, button_test.py, config.py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]
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2026-05-27 Enhance button handling and boot sequence management
    - Introduced new tunables for button double-tap and multi-tap timing, improving responsiveness and user interaction.
    - Refactored the ModeManager to implement a structured boot sequence, providing detailed status updates during initialization.
    - Updated UI rendering during boot to display progress, step, and device information, enhancing user feedback.
    - Improved button classification logic to treat triple taps as doubles, streamlining navigation.
    - Added unit tests for new button timing functionality and boot sequence behavior, ensuring reliability and correctness.
    [button.py, config.py, main.py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]
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2026-05-27 Refactor button handling and update display settings
    - Adjusted button classification to recognize triple taps, enhancing user interaction.
    - Modified display settings to reduce the minimum refresh rate and prevent UI freezing.
    - Updated button tunables to improve responsiveness and clarify button wiring configurations.
    - Enhanced event handling to prioritize button events over sensor data, ensuring critical inputs are processed.
    - Refactored unit tests to validate new button behaviors and display settings, ensuring reliability in user interactions.
    [button.py, config.py, events.py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]
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2026-06-20 Fix food classification, harden DB, replace hotspot with mDNS + Wi-Fi UI
    Bug fixes
    - foods.classify: dequantize uint8/int8 model output using the tensor's
    (scale, zero_point). Previously raw quantized scores (0-255) were softmaxed,
    collapsing the top class to ~1.0 confidence and defeating
    food_min_confidence — low-quality guesses were accepted as certain.
    - foods.reload: reset all model state (input/output details, labels), not just
    the interpreter, so a model swap can't mis-map outputs.
    - foods._ensure_model: log a clear one-time warning when the TFLite model is
    absent instead of a silent debug line.
    - logger.Logger: self-heal a malformed SQLite DB on open (quarantine to
    .corr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
    [config.py, display.py, manager.py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]
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2026-06-20 Network screen: full-screen scannable QR + small back button
    The OLED Network screen is now just a large QR of the dashboard URL plus a
    small back chevron — nothing else. Added netinfo.qr_image_fit() which renders
    the QR at the largest integer module scale that fits the panel (error='l' to
    maximise module size), so on the 160x128 TFT it fills ~116px at 4px/module.
    Scanning the QR opens http://<hostname>.local in a phone browser.
    [manager.py, ui.py]
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2026-06-21 Make food capture actually detect food: bundle real classifier
    The food-photo flow never recognized anything because no model shipped
    (only the labels file), so classify() always returned None and the result
    screen dead-ended on "unknown · 0/100". Fixes:
    - Bundle Google's AIY Food V1 quantized TFLite model (2024 food classes,
    ~20 MB) + its label map; un-ignore it so it ships in git and to the SD.
    - foods.py: load via ai-edge-litert / tflite-runtime / tensorflow (whichever
    is present); resolve_label now keeps the *detected* dish name and maps it to
    GERD risk via foods.json (exact/alias/whole-word) with a clinically-grounded
    keyword fallback (fried/fatty/citrus/etc. → HIGH, veg/gra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
    [config.py, manager.py, ui.py]
2026-06-21 Seamless Wi-Fi setup (captive portal) + keep the Pi clock synced
    Wi-Fi onboarding is now one scan: joining the "UpRight-Setup" AP auto-opens
    the Wi-Fi picker, no URL to type.
    - install.sh drops a NetworkManager shared-dnsmasq config that resolves every
    domain to the gateway (10.42.0.1) while the setup AP is up.
    - web/app.py: a before_request hook redirects OS captive-portal probes
    (Android/iOS/Windows/Firefox) and foreign hosts to the setup page during
    setup mode, so the phone pops its sign-in sheet straight onto it.
    - New clean, login-free, self-contained setup page (templates/setup.html):
    scan → tap network → inline password → connect; on success it shows the
    dashboard link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
    [main.py, ui.py]
2026-06-21 timesync: also run when only the set-time helper is present
    So hand-deployed boards (firmware files copied to the SD without apt-installing
    chrony) still self-correct the clock via the HTTP-Date fallback on boot.
2026-06-21 Wi-Fi: make the setup AP actually broadcast on the Pi Zero 2 W
    On a real boot the UpRight-Setup AP never appeared. Hardened the AP path:
    - start_ap() now frees the single radio first (a saved network that NM keeps
    auto-retrying — e.g. an out-of-range home SSID — otherwise hogs wlan0 and
    blocks AP activation), and recreates the profile each time with explicit
    WPA2/RSN ciphers (proto rsn, pairwise/group ccmp) and a fixed 2.4GHz channel.
    The bare `key-mgmt wpa-psk` form can leave wpa_supplicant unable to beacon on
    some brcmfmac builds.
    - provisioning boot grace 30s→12s (interval 20s→15s) so the AP shows quickly
    when the saved network is unreachable.
    - OLED online Network scr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
    [ui.py]
2026-06-24 Fix root cause: hand wlan0 to NetworkManager (+ i18n, water log, no-HRV, etc.)
    THE network bug: the device "won't connect to anything and the setup AP won't
    broadcast." Root cause found by reading the SD: Raspberry Pi Imager configured
    Wi-Fi the old ifupdown way in /etc/network/interfaces AND NetworkManager was left
    `[ifupdown] managed=false` — so NM never managed wlan0. The entire firmware Wi-Fi
    stack (setup AP + Settings → Network) is nmcli-based, so it silently couldn't
    touch the radio.
    Fix:
    - install.sh now hands wlan0 to NetworkManager: strips the wlan0 stanza from
    /etc/network/interfaces, migrates any ifupdown Wi-Fi into an NM keyfile, and
    drops /etc/NetworkManager/conf.d/10-u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
    [config.py, events.py, i2c_probe.py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]

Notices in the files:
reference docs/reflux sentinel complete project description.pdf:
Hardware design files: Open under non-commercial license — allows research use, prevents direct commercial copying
